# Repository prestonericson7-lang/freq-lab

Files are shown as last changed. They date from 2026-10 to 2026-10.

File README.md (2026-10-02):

# freq-lab

**A GPS-disciplined space-weather monitoring stack, built on an FPGA.**

An 8-station VLF solar-flare receiver that watches U.S. Navy transmitters for the
ionospheric signature of a solar flare, lightning geolocation by time-of-arrival across
stations, a 30 MHz riometer for cosmic-noise absorption, and a live multi-station
dashboard — all timed to GPS and verified to the bit before it touches hardware.

Verilog on a Zynq-7020 (PZ7020-StarLite), firmware on Teensy 4.1 / ESP32 / STM32, Python
host tools and a browser dashboard, plus the supporting instrumentation: a NIST
SP 800-90B-tested hardware random number generator, a digital lock-in amplifier, a
coincidence photon counter and a two-channel correlator.

**Every design is verified before it touches hardware:**

- **343 automated checks, all green**, in one command: `python run_all_tests.py`
- Two FPGA bitstreams that **close timing in Vivado 2026.1 with zero critical warnings**
- FPGA simulations checked **bit-exact against independent Python reference models**
- Firmware signal processing lifted into headers and **tested on a PC** (no hand-waving)

I don't overclaim. **Nothing here has run on real hardware yet** — everything is compile-,
simulation- or model-verified, and [STATUS.md](STATUS.md) says exactly what's proven and what
still needs a bench. When I say it works, there's a logged test behind it.

**Start here:** [STATUS.md](STATUS.md) (what's verified) · [WIRING.md](WIRING.md) (every pin,
every board) · [docs/station-setup.md](docs/station-setup.md) (build the VLF receiver station).

Toolchain to build/run it yourself: Python 3 (numpy, pyserial, matplotlib for plots) for the host
tools; the Arduino IDE or `arduino-cli` with the Teensy, ESP32 and STM32 cores for the sketches;
Xilinx Vivado (tested 2026.1) for the FPGA bitstreams, or just load the pre-built `.bit` files in
`fpga/*/build/`; Icarus Verilog + g++ to re-run the simulations and PC tests.

| Folder | Runs on | What it does | Checked |
|---|---|---|---|
| `teensy/resonance_sweep` | Teensy 4.1 + MPU-6050 + any exciter | Swept-sine lock-in, 0.05–400 Hz: resonance curve, Q, phase-locked tracking, ring-down | Compiles. Against a simulated resonator: f0 37.281 vs 37.271 Hz, Q 18.0 vs 18.0, tracker followed a drift from 37.3 to 38.0 Hz, ring-down time exact |
| `teensy/body_resonance` | Teensy 4.1 + up to six MPU-6050 | Vibration spectra, transfer function between two points on a body or structure, heartbeat recoil (ballistocardiogram) | Compiles. Simulated: 7 Hz line read 4997 µg of 5000; transfer peak 3.95 at 4.88 Hz vs 4.03 at 4.92; heart rate 72.0 of 72 |
| `teensy/hemisync_gen` | Teensy 4.1 + headphones | Six binaural tone pairs, exact beat frequencies, pink/surf noise, blind binaural / monaural / sham sessions | Compiles. Synth output measured: 100.000 / 104.000 Hz, beat 4.000 Hz, noise −10.0 dB |
| `teensy/elf_logger` | Teensy 4.1 + amplifier + coil or electrodes, GPS optional | 0.25–45 Hz spectrum logger with mains rejection, SRI's 19 bands, the first three Earth-ionosphere modes, GPS-stamped raw waveform | Compiles. Simulated front end with 1 V of mains on it: a 2 µV line read 1.4135 µV rms of 1.4144; noise floor within 3 %; 240 Hz mains harmonic did not fold into the band; 204 of 204 GPS second marks placed on the right sample |
| `teensy/strobe_driver` | Teensy 4.1 + LED(s) | Flashing-light driver, 0.1–100 Hz, randomized trial blocks (SRI's 0 / 6 / 16 Hz layout), glide, flash and trial markers, light-sensor check | Compiles. Every 50 µs tick simulated: 16 Hz period and width exact, 36 trials of exactly 10.00000 s with 0 / 60 / 160 flashes, blind order kept off the screen and matching the SD key |
| `teensy/cc1101_scanner` | Teensy 4.1 + CC1101 | Sub-GHz spectrum scanner, 300–928 MHz, variable RBW, peak hold, CSV sweep export | Compiles (Teensyduino 1.62, RadioLib 7.7.1) |
| `fpga/lockin` | PZ7020-StarLite (Vivado) | DDS + sigma-delta drive + on-chip 12-bit ADC + digital lock-in + resonance tracker, UART-controlled, up to about 100 kHz | Simulates end to end (iverilog): amplitude within 0.1 %, lag within 0.4°, tracker pulled 19.0 kHz onto a 20.0 kHz resonance. Synthesizes for xc7 (yosys). Vivado 2026.1: builds, timing met (WNS +11.9 ns at 50 MHz), 3.6 % LUTs, 0 critical warnings, ~0.13 W. Not yet run on hardware |
| `fpga/photon_counter` | PZ7020-StarLite (Vivado) | Coincidence photon counter: dual detectors, programmable coincidence window, singles + coincidence counts, elapsed clock, fan PWM, UART register protocol | Simulates end to end (iverilog): 12 checks pass — ID read, window write/readback, start/stop, singles and coincidence counts checked exactly (same-clock pairs counted, each pulse in at most one pair, none outside the window), error handling. Vivado 2026.1: builds, timing met (WNS +11.6 ns), 1.1 % LUTs, 0 critical warnings, ~0.11 W. Not yet run on hardware |
| `fpga/correlator` | PZ7020-StarLite (Vivado) | Two-channel cross-correlator: dual XADC (VAUX1 + VAUX9, ~195 kS/s each), DC-removed accumulation, circular-buffer lag queries, GPS PPS timestamping, fan PWM, UART register protocol | Simulates end to end (iverilog): 7 tests pass — ID read, live ADC reads, 100-sample acquisition with sin/cos test signals, accumulator readback (N=100 exact), lag query, error handling, GPS PPS counter. Vivado 2026.1: builds, timing met (WNS +8.1 ns), 2.4 % LUTs, 0 critical warnings, ~0.12 W; channel B is JM1-9/11 (E18/E19). Known limitation: nonzero-lag queries wrap around the 256-sample buffer (lag-0 coherence is exact). Not yet run on hardware |
| `fpga/vlf_sid` | PZ7020-StarLite (Vivado) | 8-station VLF solar-flare (SID) receiver: XADC at 390.6 kS/s, eight NCO + CIC channels (NLK, NPM, NAA, NML, NAU, NWC, JJI + a noise reference), power per GPS second, lightning-spike and clipping monitors, UART register protocol | Simulates end to end (iverilog): 33 testbench checks pass, and every decimated I/Q value of all 8 channels matches a bit-exact Python model; agrees with an ideal floating-point receiver within 0.003 dB, 80 dB rejection 400 Hz off-channel. Vivado 2026.1: builds, timing met (WNS +6.3 ns), 17 % LUTs, 50 DSPs, 0 critical warnings, ~0.15 W. Not yet run on hardware |
| `fpga/vlf_sid_v2` | PZ7020-StarLite (Vivado) | vlf_sid plus lightning (sferic) capture: threshold trigger, GPS-second + 20 ns clock stamps, 64-sample pre/post-trigger snapshots, 32-event FIFO, UART registers 40–49 and 60–7F; for a time-of-arrival lightning network | Simulates end to end (iverilog): 59/59 testbench checks (all of v1's + events over the UART), 19/19 Python checks (all of v1's + triggers at the predicted samples, every event's GPS second, exact 20 ns count, polarity, peak and all 64 snapshot samples vs the stimulus). Vivado 2026.1: builds, timing met (WNS +4.5 ns), 17.9 % LUTs, 7.5 BRAM tiles, 50 DSPs, 0 critical warnings, ~0.16 W. Not yet run on hardware. See `fpga/vlf_sid_v2/README.md` |
| `stm32/rf_resonance` | STM32 + SX1262 (DX-LR20 kit) | RF resonance probe: CW + swept-frequency transmission from one radio to another, measures insertion loss vs frequency to find cavity or tissue resonances | Compiles with arduino-cli (STM32 core 3.0.0 + RadioLib 7.7.1) for F103C8 (63.8 KB, 97 % flash) and F411CE: core 3.x needs RadioLib's pin casts, passed by `stm32/rf_resonance/build.bat` (the plain arduino-cli build fails in RadioLib's HAL). MAX_SWEEP 500 to fit the F103C8's 20 KB RAM; raise to 2000 on boards with ≥64 KB |
| `tools/lockin_host.py` | PC (Python + pyserial) | Sweeps, Q, tracking and delay calibration for the FPGA lock-in | Run against a software model of the FPGA: f0 439.93 of 440, Q 39.97 of 40 |
| `tools/photon_host.py` | PC (Python + pyserial) | Live counts, run management, accidental subtraction, CSV export for the photon counter | Not yet tested against hardware |
| `tools/correlator_host.py` | PC (Python + pyserial + numpy) | Acquisition, lag sweep, coherence computation, CSV/plot export for the correlator | Not yet tested against hardware |
| `tools/vlf_host.py` | PC (Python + pyserial, matplotlib for plots) | VLF receiver: info, input level, 10–50 kHz station scan, 1-second CSV logging with GOES X-ray flux, plots; `--station/--push` upload to the server; `sferics` (v2) logs strokes with UTC to the microsecond + 20 ns clock + snapshot | Run against a simulated board: scan found and named the stations, GPS sample-clock correction worked (+29.7 ppm of +30), GOES feed fetched and plotted. `tools/test/test_vlf_host.py` (fake v2 board + stub server): 16/16 — uploads, three strokes stamped within 20 ns of the injected times, queued delivery through an outage. Not yet tested against hardware |
| `tools/sid_detect.py` | PC (Python) | Solar-flare (SID) detector: trend-following baseline, 20-s mean onset confirmation, frozen baseline during events, 2-channel sustain, GOES confirmation, multi-station flag; also runs standalone over a CSV | `tools/test/test_sid_detect.py`, a synthetic day with 9 dB sunrise/sunset ramps, 200 lightning spikes, a one-channel step and two flares (+3.2, −2.0 dB): 14/14 — both flares found within 90 s of onset at +3.55 / −2.03 dB, 0 false events, GOES class C4.2 confirmed on the right one, multi-station flag right |
| `tools/sid_server.py` + `dashboard/index.html` | PC (Python stdlib only) | Station network server: SQLite store, JSON API, background flare detector + GOES fetcher, cross-station stroke matching (3 ms), and a dependency-free live dashboard (levels, GOES, strokes/min, alerts, time-of-arrival table) | `tools/test/test_sid_server.py`: two stations × 3 h ingested, strokes matched across stations to 1200 µs, detector creates GOES-confirmed multi-station alerts without duplicates, every endpoint and the dashboard served, bad input refused |
| `tools/riometer_host.py` | PC + RTL-SDR (`rtl_power`) | 30 MHz riometer / 245 MHz solar-burst logger: band power with interferer rejection, sidereal quiet-day curve (upper quartile over 7 days), absorption or enhancement in dB, CSV, upload | `tools/test/test_riometer.py`, 3 sidereal days synthetic with a +20 dB interferer bin and a 2.5 dB absorption event: 8/8 — band power within 0.23 dB of the true sky with the interferer dropped, the event read 2.56 dB, nothing outside it above 0.25 dB |
| `torsion_pendulum` | 2-liter bottle + 3D-printed parts + ESP32-S3 CAM (GC2145) + PC | SRI's 1974 bell-jar torsion pendulum test: sealed, static-shielded, backlit rotor tracked by the camera (rotor angle against two reference squares), blind random PUSH/REST schedule, hash-chained session log, exact randomization statistics, empty-room and warm-bottle controls | Parts watertight and fit-checked; tracker on synthetic frames 0.1-0.2 mrad/frame, camera movement cancelled; firmware compiles (Arduino-ESP32 3.3.12 and 2.0.17); statistics give 5 % false alarms on 200 simulated null sessions. Not yet run on hardware. See `torsion_pendulum/README.md` |
| `teensy/fpga_uart_bridge` | Teensy 4.1 | USB to FPGA serial pass-through | Compiles |
| `teensy/vlf_station` | Teensy 4.1 + vlf_sid FPGA + GPS | GPS-aware station bridge: passes the FPGA UART to the PC AND reads GPS NMEA (Serial2, pin 7) + 1PPS (pin 2) so `vlf_host.py --gps-bridge` stamps windows with true GPS UTC; `@gps`/`@pps`/`@id` bridge commands. For the full-rig station (FPGA + Teensy + ESP32 + SDR + GPS) — see `docs/station-setup.md` | Compiles (50 KB). NMEA parser PC-tested (`teensy/vlf_station/test/pc_test.cpp`, 11/11). Not yet run on hardware |
| `teensy/schumann_monitor` | Teensy 4.1 + ADS1256 (24-bit) + coil preamp + ball antenna | Two-channel ELF monitor: H and E multiplexed at 1000 SPS each, mains notches + 45 Hz low-pass, 4096-point Welch spectra, the five Schumann modes (centre Hz, pT/√Hz, floor ratio), E/H wave impedance with coherence at modes 1–2, GPS stamps, SD, JSON reports | Compiles (Teensyduino 1.62): 105 KB code, 145 KB RAM1 free. Filters and mode finder are the ones verified in `elf_logger` on a simulated front end. Not yet run on hardware |
| `esp32/schumann_gen` | ESP32 (DAC) or ESP32-S3 (PWM) + DC-coupled coil driver | Calibrated ELF field generator: 7.83 Hz + 4 harmonics (8 kS/s synthesis), current-sense field calibration in µT (coil geometry), closed-loop `target`, blinded sham sessions with a SHA-256 commitment, magnetophosphene sweep/ramp mode with a threshold button, phone web page (AP) | Compiles for esp32 (74 % flash, 15 % RAM) and esp32s3. Not yet run on hardware |
| `tools/schumann_host.py` | PC | Monitor host: reports to CSV, one-line summaries, upload to the server as kind `schumann`, live spectrum, 24 h+ history plots | `tools/test/test_schumann_host.py` (fake monitor + stub server): 6/6 |
| `teensy/rf_survey` | Teensy 4.1 + AD8318 log detector (1 MHz–8 GHz) | RF survey meter: 50 kS/s detector sampling, power-mean/peak dBm and µW/cm² per second (antenna aperture), envelope spectra 0.06–125 Hz and 12 Hz–25 kHz with named modulation lines (Wi-Fi beacon 9.77 Hz, LTE, DECT, Bluetooth, mains), pulse-interval histogram with a hysteresis detector, two-point calibration, GPS-tagged survey rows | Compiles (102 KB). Arithmetic PC-tested (`teensy/rf_survey/test/pc_test.cpp`, 18/18): calibration fit, aperture maths, power-mean level, pulse histogram on a synthetic Wi-Fi+LTE waveform (10 ms frame on top at 6 dB, 97 beacon intervals at 25 dB), peak finder and naming. Not yet run on hardware |
| `tools/rf_survey_host.py` | PC | Survey CSV, map coloured by µW/cm² (or level vs time without GPS), envelope-spectrum capture and plot, pulse listing | `tools/test/test_rf_survey_host.py` (fake meter): 7/7 |
| `teensy/sleep_cue` | Teensy 4.1 + EEG front end (+ EMG), earbuds | Closed-loop slow-oscillation cueing (Ngo 2013) + targeted memory reactivation: 30-s deep-sleep gate, SO trough detector (filter-delay compensated), cue 0.5 s after the trough, 2.5 s refractory + 6/min cap + arousal pause, SHA-256-sealed word-pair split, blinded stim/sham nights | Compiles (115 KB). Signal processing PC-tested (`teensy/sleep_cue/test/pc_test.cpp`, 22/22) on a synthetic night: gate, SO detection (≥95 µV caught, ≤65 µV rejected), cue timing (worst 8 ms), rate cap, arousal pause, SHA-256 vectors. Not yet run on hardware |
| `tools/sleep_cue_score.py` | PC | Blind scoring of a word-pair night: checks the SHA-256 commitments before scoring, permutation test of cued vs uncued recall | `tools/test/test_sleep_cue_score.py`: 8/8 (5 % null, power, commitment refusal) |
| `teensy/kirlian_logger` | Teensy 4.1 + GSR/FSR/photodiode front ends (HV rig external) | Controlled Kirlian: logs skin conductance, contact pressure and corona brightness per exposure, fits corona = moisture + pressure and reports R² and the residual; interlocks the HV (enable only during an armed exposure) but never generates it | Compiles (88 KB). Fit PC-tested (`teensy/kirlian_logger/test/pc_test.cpp`, 8/8): recovers coefficients, drops R² and recovers a hidden component, refuses singular/collinear inputs. Not yet run on hardware |
| `teensy/nuisance_logger` | Teensy 4.1 + MPU-6050 + fluxgate + mic + mains pickup | Logs a signal beside vibration, B-field, sound and mains and vetoes the ordinary cause: per-sample windowed correlation flags when an excursion is explained by a nuisance (the 8 Hz mount resonance, #133; 60 Hz everywhere) | Compiles (92 KB). Veto core PC-tested (`teensy/nuisance_logger/test/pc_test.cpp`, 10/10): genuine signal not vetoed, vibration-as-signal and continuous/impulsive mains vetoed, no false blame. Not yet run on hardware |
| `fpga/trng` | PZ7020-StarLite (Vivado) | Ring-oscillator TRNG (#73): 16 ring oscillators → SP 800-90B health tests (Repetition Count + Adaptive Proportion) → von Neumann debiaser → LFSR conditioning → 32-bit words → FIFO; on-chip temperature and VCCINT logged; output withheld while a health test is tripped | Simulates end to end (iverilog, entropy backdoor): 9 testbench + 33 Python checks, every output word, counter, health flag and FIFO read bit-exact vs a model across balanced/stuck/biased streams. Vivado 2026.1: builds, timing met (WNS +12.6 ns), 570 LUTs (1 %), 0 critical warnings, the 16 ring-oscillator loops flagged allowed, ~0.11 W. Not yet run on hardware. See `fpga/trng/` |
| `tools/trng_host.py` | PC | TRNG host: info + die temp, word/byte streaming, live health, config, `selftest` (125 kB sample, monobit/runs/chi-square + die-temp log, the SRI 1980-style certification run) | `tools/test/test_trng_host.py` (fake board): 14/14 (health-alarm stop, config, streaming, stats pass good / fail biased) |
| `tools/blindhash.py` | PC | Blind randomization + pre-posted SHA-256 commitment (#158): draw a schedule, seal it, verify it, score it (two-sided permutation by default; one-sided only with a pre-registered direction) | `tools/test/test_blindhash.py`: 17/17 (tamper-evident, calibrated null, order-independent p — a real statistical bug the red-team pass caught) |
| `tools/shield_audit.py` | PC | Shielding attenuation vs frequency (#134, #160) from lock-in / CC1101 / VLF sweep CSVs, with skin-depth theory: shows the ELF hole in an RF-tight cage | `tools/test/test_shield_audit.py`: 10/10 (attenuation maths, format reading, copper/mu-metal skin depth) |
| `tools/cavity_readout_host.py` | PC + SX1262 pair / RTL-SDR | Passive-cavity resonator test-tone readout (#190, #191, the Great Seal demo): recover a known test tone off a tuned cavity, measure recoverable SNR vs illuminator power | `tools/test/test_cavity_readout.py`: 11/11 (carrier finding, AM/PM demod, SNR-vs-depth, power-step threshold) |

## Teensy sketches: first run

Arduino IDE, board Teensy 4.1, upload, open the serial monitor, type `help`.

- **resonance_sweep**: fix the MPU-6050 and the exciter to the object, then
  `amp 0.2`, `sweep 5 200 100 log`, `ringdown <peak Hz> 5 5`, `track 60`.
- **body_resonance**: `scan`, then `spec 60` for spectra, `tf 0 240` for the transfer
  function from sensor 0 to the others, `bcg 2 120` for the heartbeat recoil at sensor 2.
- **hemisync_gen**: `preset patent4`, `vol 0.15`, `run 10`. For a test that means something:
  `blind patent4 10`, write down what you noticed, then `reveal`.
- **elf_logger**: `gain 1000`, `mains 60`, `raw on`, `start 300`. `live` prints the full spectrum.
- **strobe_driver**: read the warning at the top of the file first. `arm`, `arm yes`,
  `rate 10`, `on`, `check 4`, `off`. SRI's layout: `blind on`, `sri`.
- **cc1101_scanner**: `sweep 433 434 12` scans 433–434 MHz with 58 kHz RBW.
  `peak`, `hold on`, `csv` dumps the last sweep.
- **schumann_monitor**: `gain h 1000`, `pga h 8`, `coil 30000 0.0158`, `ecal 1.0`,
  `start 60`. `live` prints the full H/E spectrum; `json on` for the host tool.
- **rf_survey**: `cal -20` then `cal -40` with known levels, `ant 2.44 2.0`,
  then `level`, `spec slow 60` (Wi-Fi beacon at 9.77 Hz), `pulses 30`, `survey on`.
- **sleep_cue**: battery power only with electrodes on. `gain 1000`, `vol 0.05`,
  `test` to set the volume, `pairs 60`, then `night` (blind) or `mode sham` + `start`.
- **nuisance_logger**: `window 64` (for 60 Hz) or `256` (for 8 Hz), `start 300`;
  `report` shows which nuisance explained the signal excursions.
- **kirlian_logger**: build the interlocked HV rig first. `gsrcal`, `vary moist 8`,
  `expose` each, then `fit` for R² and the residual. HV safety is on you.
- **vlf_station**: the GPS-aware bridge for the VLF station — no serial commands of
  its own; flash it, then talk to the FPGA through it with `vlf_host.py`. See below.

## STM32 + SX1262: RF resonance probe

Arduino IDE with STM32 board package + RadioLib. Wire the DX-LR20 kit's SPI/BUSY/DIO1
pins to the STM32 (pin map at the top of `rf_resonance.ino`). Power both radios, connect
one to each STM32, serial monitor on each.

On the transmitter: `mode tx`, `cw 915.0`, then on the receiver: `mode rx`, `measure`.
For a swept measurement: transmitter `sweep 900 928 0.1`, receiver `sweep 900 928 0.1`.

The idea is to put a sample (tissue, water, crystal, cavity) between the two antennas and
look for absorption dips or resonance peaks in the insertion-loss-vs-frequency curve.

## FPGA lock-in

### Wiring (JM1, even-numbered row)

```
JM1-2  3.3 V        JM1-4  GND
JM1-6  ADC +   0 .. 1.0 V ONLY          JM1-8  ADC -   -> GND at the sensor
JM1-10 drive   -> 1 kΩ -> node -> 10 nF -> GND      (node = analog sine, 0..3.3 V)
JM1-12 sync    square wave at the drive frequency
JM1-14 FPGA TX -> adapter RX (or Teensy pin 0)
JM1-16 FPGA RX <- adapter TX (or Teensy pin 1)
```

Fan pins JM1-5 / JM1-7 behave exactly as in `fan_top.v`, so the fan keeps running.

Loop-back for a first test and for `cal`: node -> 33 kΩ -> JM1-6, and 10 kΩ from JM1-6 to GND
(divides by 4.3, so even 3.3 V at the node is 0.77 V at the pin). JM1-8 to JM1-4.

A sensor goes in the same way: bias JM1-6 to about 0.5 V (56 kΩ to 3.3 V, 10 kΩ to GND),
couple the sensor through 100 nF, and keep its swing under ±0.4 V.

### Build and load

```
cd fpga/lockin
vivado -mode batch -source build.tcl      # writes lockin_top.bit
vivado -mode batch -source program.tcl    # boot jumper on JTAG, JTAG Type-C connected
```

LED1 blinks once a second when the fabric is running. LED2 toggles on every finished
lock-in window.

### Use

```
pip install pyserial
python tools/lockin_host.py COM7 id
python tools/lockin_host.py COM7 cal
python tools/lockin_host.py COM7 sweep 50 5000 200 --log --amp 0.2 --out curve.csv
python tools/lockin_host.py COM7 track 440 --step 0.05
python tools/lockin_host.py COM7 off
```

Drive range: micro-hertz steps up to about 100 kHz (the RC filter's corner is 16 kHz;
change the capacitor for higher drive frequencies). ADC rate 390.6 kS/s.

### Re-run the simulation

```
cd fpga/lockin
iverilog -g2005 -DSIMULATION -o tb sim/tb_lockin.v hdl/*.v && vvp tb
```

## FPGA photon counter

Coincidence counter for biophoton detection experiments (Gurwitsch mitogenetic radiation,
SRI-style photomultiplier setups). Two detector inputs, programmable coincidence window,
64-bit singles and coincidence counters, elapsed clock for rate computation.

### Wiring (JM1, even-numbered row)

```
JM1-2  3.3 V             JM1-4  GND
JM1-6  det_a  detector A pulse input (3.3 V logic, rising edge = photon)
JM1-8  det_b  detector B pulse input
JM1-10 gate   counting enable (active high, tie to 3.3 V for always-on)
JM1-14 FPGA TX -> adapter RX
JM1-16 FPGA RX <- adapter TX
```

Fan on JM1-5 / JM1-7.

### Build and load

```
cd fpga/photon_counter
vivado -mode batch -source build.tcl
vivado -mode batch -source program.tcl
```

### Use

```
python tools/photon_host.py COM7     # connects, prints the ID, then gives a photon> prompt
photon> window 10                    # coincidence = A and B within ±10 ticks (±200 ns)
photon> run 10                       # count for 10 s, then print singles, coincidences, elapsed
photon> rate                         # counts per second
photon> accidental                   # chance overlaps vs real coincidences
photon> csv run1.csv 60 5            # five 60 s runs saved to run1.csv
photon> quit
```

### Re-run the simulation

```
cd fpga/photon_counter
iverilog -o tb sim/tb_photon.v hdl/*.v && vvp tb
```

## FPGA two-channel correlator

Cross-correlator for ELF two-station experiments. Two on-chip XADC channels
(VAUX1 + VAUX9, ~195 kS/s each), DC-removed accumulation via the identity
`sum((a-ma)(b-mb)) = sum(ab) - sum(a)*sum(b)/N`, circular buffer for lag queries
up to ±MAX_LAG samples, GPS PPS timestamping for multi-station synchronization.

### Wiring (JM1, even-numbered row)

```
JM1-2  3.3 V             JM1-4  GND
JM1-6  VAUX1+  channel A analog input (0..1.0 V)
JM1-8  VAUX1-  -> GND at sensor
JM1-9  VAUX9+  channel B analog input (0..1.0 V)   (odd row, ball E18)
JM1-11 VAUX9-  -> GND at sensor                    (odd row, ball E19)
JM1-18 gps_pps GPS 1PPS input (3.3 V logic, optional)
JM1-14 FPGA TX -> adapter RX
JM1-16 FPGA RX <- adapter TX
```

Fan on JM1-5 / JM1-7.

### Build and load

```
cd fpga/correlator
vivado -mode batch -source build.tcl
vivado -mode batch -source program.tcl
```

### Use

```
python tools/correlator_host.py COM7  # connects, prints the ID, then gives a corr> prompt
corr> adc               # live reading of both inputs (about 2048 = 0.5 V on the bias network)
corr> window 100000     # samples per window: 100000 = 0.5 s, up to about 1900000 = 10 s
corr> stream 5          # 5 windows back to back, coherence (-1 .. +1) for each
corr> lagplot 16        # last window's correlation at offsets -16..+16 samples (5.12 us each)
corr> csv out.csv 50    # 50 windows saved to out.csv
corr> quit
```

### Re-run the simulation

```
cd fpga/correlator
iverilog -DSIMULATION -o tb sim/tb_correlator.v hdl/*.v && vvp tb
```

## FPGA VLF solar-flare receiver (vlf_sid)

Listens to 8 Navy VLF transmitters at once and logs their strength every second, so
a solar flare shows up as a step in the daytime stations at the moment the GOES X-ray
curve rises. Same JM1 wiring as the lock-in (antenna preamp on JM1-6/8, UART on 14/16,
optional GPS PPS on 18). Full details, front end and register map:
[fpga/vlf_sid/README.md](fpga/vlf_sid/README.md).

```
fpga\build_vlf_sid.bat                          (double-click: Vivado build)
python tools/vlf_host.py COM7 level             set the preamp gain
python tools/vlf_host.py COM7 scan              10-50 kHz spectrum, names the stations
python tools/vlf_host.py COM7 log --goes        1 line per second + GOES X-rays to CSV
python tools/vlf_host.py plot vlf_2026-10-02.csv --goes goes_2026-10-02.csv
```

**Version 2 (`fpga/vlf_sid_v2`)** adds lightning time-of-arrival capture (20 ns
GPS-relative stamps) on top of everything above; build it with
`fpga\build_vlf_sid_v2.bat`. **For a full receiver station** (FPGA + a GPS-aware
Teensy bridge + an RTL-SDR riometer complement + GPS/PPS), including the exact
wiring, the GPS convention and `vlf_host.py --gps-bridge` for true GPS time, see
[docs/station-setup.md](docs/station-setup.md). Product-line kit docs for the
space-weather, Schumann, RF-survey and biofeedback lines are in [docs/](docs/).

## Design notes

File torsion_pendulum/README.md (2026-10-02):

# Torsion pendulum in a bottle (FOIA list #2)

SRI reported in 1974 that a person could disturb a torsion pendulum sealed in a bell
jar. The pendulum was three 100 g balls on a metal fiber, read out by a laser 1.5 m
away. The change from baseline was "often 5:1" from 1 m and "typically 2:1" from
12 m. The runs were randomized, but no statistics were done.

This rig repeats that test with the known culprits handled:

- **Static electricity:** a grounded foil shield blocks it.
- **Body heat:** a warm-water-bottle control session measures how much it moves the rotor.
- **Drafts:** the chamber is sealed.
- **Camera movement:** reference squares cancel it out.
- **Wishful analysis:** the random schedule is fixed before each session, every session is logged, and the statistics are exact.

How to read the result:

- **Grade C claim.** No one has shown it works under conditions like these. A clean
  null result is the expected outcome, and it is a real result.
- **An effect would show in one session.** SRI's claimed 2:1 to 5:1 effect is huge
  next to this rig's noise.

```
              knob (sets the zero)      ESP32-S3 CAM, lens down
                    |                       |
   lid  ===========[O]====[ sled  window ]=====      <- 132 mm plate
          \         |                        /       <- 45 deg cone: the top rim of the sleeve wedges on it
           \________|_______________________/           (any rim 85-120 mm across); tape over the joint
            |       |                       |
            |     fiber (one strand of      |        the bottle's straight middle, cut off top and bottom
            |     jumper wire)              |        ("the sleeve", 150-230 mm tall), foil-wrapped outside
            |       |                       |
            |  [==O===o===O==]  rotor: 2 quarters sealed inside, 20 mm above the floor
            |  []  --paper--  []            |        paper target glued to the floor, squares at +/-30
           /________________________________\        <- 45 deg cone: the bottom rim slides over it
   base   |          |  LED  |               |       <- 30 mm base; 94 mm backlit window in the floor,
          |__________|_______|_______________|          open underneath; the LED sits on a puck on the table
```

A real 2-liter bottle is 100-120 mm across and 300-330 mm tall depending on the brand,
with a five-footed base that is domed inside and a long curved shoulder. So the bottle
is used only for its clear wall: it is cut twice, and the printed lid and base each
carry a 45-degree cone that any rim between 85 and 120 mm wedges onto. The floor is
printed and flat, and nothing in the design depends on the bottle's diameter.

## Parts

| Item | Notes |
|---|---|
| `torsion_pendulum.3mf` | Bambu Studio project, 4 plates: lid, base, rotor, knob + camera sled + LED puck. PLA, white for the base (the floor's window is the light diffuser). The rotor is set to 100 % infill and needs a **pause at 3.40 mm** to drop one US quarter into each pocket. |
| 2-liter soda bottle | Empty, clean, label off. Any brand: only its straight middle is used. |
| ESP32-S3 CAM | Your Meshnology GC2145 board, plus a USB-C cable. |
| 2 US quarters | The rotor's weights. |
| Fiber | One strand pulled out of a stranded jumper wire, about 25 cm long. A strand from a usual 26 AWG Dupont jumper is 0.16 mm and gives a swing period of about 5 s; a 28 AWG strand (0.127 mm) gives about 8 s and 2.5x the sensitivity. Thinner is better; `calibrate` measures whatever you use. |
| 5 mm white LED + 470 ohm resistor | Backlight, powered from the camera board's 5V and GND pins with female jumpers. A *diffused* (cloudy) LED lights the floor evenly; if yours is water-clear, scuff its dome with sandpaper. Use 220 ohm if the picture is too dark. |
| Aluminium foil + 1 jumper wire | Static shield around the sleeve, wired to the board's GND. |
| 2x M3x10 screws + 2x M3 nuts | Hold the camera sled to the lid. M3x12 also fits. |
| Hot glue or superglue, a glue stick | Fix the fiber ends and the camera board; the glue stick holds the paper target to the floor. |
| Clear tape | Seals the camera window and the two sleeve joints. |
| Plain printer paper | For `paper_target.pdf`, printed at 100 %. |

## Build

1. **Cut the bottle twice.** Stand it on a table and mark the lines with a marker held
   on a stack of books while you turn the bottle.
   - *Bottom cut:* about 40 mm up, just above the feet, where the body has become round.
     If your bottle has a grip or waist low down, cut above it.
   - *Top cut:* in the shoulder, where the bottle has narrowed to about 90 mm across
     (anywhere between 85 and 120 mm is fine; the lid's cone takes any of it). Cutting
     there keeps the most height.
   - Both rims must be round: not through a grip dent or a rib. Aim for a sleeve
     150-230 mm tall; 180-210 is typical. Trim the rims with scissors so they are even.
2. **Print the parts.** The plates are already oriented: lid top-face-down (cone up),
   base floor-down (its well opens upward), rotor flat, knob face-down. For the rotor
   (plate 3), drag the layer slider to 3.40 mm, right-click, and choose *Add pause*.
   When the printer pauses, drop one quarter flat into each pocket and resume.
3. **Paper target.** Print `paper_target.pdf` at 100 % ("Actual size"). Check that the
   scale bar measures 50 mm, cut out one 96 mm disc, and glue-stick it onto the base's
   floor with the two squares lined up with the small notch on the floor's edge.
4. **LED puck.** Push the LED up through the puck's centre hole from below until its
   flange seats in the recess; bend the legs flat into the groove, with the resistor
   on one leg, and run two wires out along the groove. (The two outer holes are for
   extra LEDs if one is not bright enough.) Put the puck on the table, LED up, and set
   the base over it with the base's wire channel over the wires.
5. **Lid.**
   - Put clear tape over the camera window from the *underside*.
   - Push 2 M3 nuts into the hex pockets under the lid.
   - Bolt the camera sled on top with the 2 M3x10 screws.
6. **Knob and fiber.** Glue one end of the strand about 6 mm into the hole at the tip
   of the knob's pin. Thread the fiber down through the lid's centre hole and seat the
   knob. Friction holds it; turning it sets the rotor's resting angle (ticks every 10°).
7. **Dry fit and measure.** Slide the sleeve's bottom rim over the base's cone and press
   it down until it wedges. Drop the lid's cone into the top rim. Measure from the table
   to the lid's top face: call it H. Take the lid off again.
8. **Hang the rotor.** The free fiber length, from the pin's tip to the top of the
   rotor's hub, is **H minus 74 mm**. Cut the strand 8 mm longer than that, push the
   extra all the way down the hub's hole and glue it. The rotor then hangs 20 mm above
   the floor; anywhere from 10 to 30 mm works.
   Let it hang overnight: a fresh copper strand creeps for a few hours, then settles.
9. **Shield.** Wrap the outside of the sleeve in one layer of foil and tape it. Tape the
   bare end of a jumper wire to the foil, and plug the other end into the board's GND.
10. **Close it up.** Lower the rotor into the sleeve and seat the lid's cone in the top
    rim. Turn the lid so its engraved arrow points the same way as the floor's notch
    (the squares then lie along the arrow). Run clear tape round both joints, from the
    printed part onto the bottle.
11. **Camera.** Lay the board camera-side down on the sled's rails, lens over the window,
    with the rest of the board pointing outward, away from the knob. Tack it with hot
    glue, or use zip ties through the slots. Wire the LED's two leads to the board's
    5V and GND.
12. **Flash the board.** In the Arduino IDE, open `firmware/torsion_cam/torsion_cam.ino`
    and pick these settings, then upload through the USB-C port marked COM/UART:
    - Board: "ESP32S3 Dev Module"
    - PSRAM: "OPI PSRAM"
    - Flash Size: "16MB"
    - USB CDC On Boot: "Disabled"

    The firmware finds the camera's pin layout by itself.

## Set up and check (PC: `pip install pyserial numpy scipy pillow matplotlib`)

```
python host/torsion_host.py COM8 snap        # saves a PNG of what the camera sees, with what it measures
python host/torsion_host.py COM8 live        # live angle, swing and period
python host/torsion_host.py COM8 calibrate   # follow the prompts: one knob tick clockwise, then back
```

**Snap:** the PNG should show:

- the rotor outlined in red, whole, inside the lit window;
- both squares in blue boxes;
- the lit window circled in green.

Turn the knob until the rotor lies *across* the line of the squares, not along it.

**Calibrate** measures:

- the swing period (about 5 s with a 0.16 mm strand, 8 s with 0.127 mm) and how fast
  it dies out;
- the torsion constant, which turns angle into torque;
- which way "clockwise" reads on the camera.

## The experiment

Decide the plan before you collect any data, and stick to it. This is the default:

- 2 warm-bottle sessions (`--kind warm`);
- 10 empty-room sessions (`--kind empty`);
- 10 agent sessions (`--kind agent`), alternated with the empty ones.

Each session lasts 22 minutes:

- 5 minutes settling;
- 16 one-minute periods, 8 PUSH and 8 REST in random order;
- 1 minute tail.

```
python host/torsion_host.py COM8 session --kind agent    # sit 1 m away; high beep = PUSH (will it clockwise),
                                                         # double low beep = REST. Stay seated the whole time.
python host/torsion_host.py COM8 session --kind empty    # start it, then leave the room within 2 minutes
python host/torsion_host.py COM8 session --kind warm     # 37 C water bottle onto the 1 m spot at PUSH,
                                                         # away to the far side at REST
python host/torsion_host.py report --plot                # checks the log, then every result and the combined score
```

**Where to set up:**

- A solid table, away from heating and AC vents, windows and direct sun, and the PC
  (it is warm).
- Mark the 1 m spot on the floor.

**What each session prints:**

- **D:** the PUSH-minus-REST deflection in mrad, with clockwise positive, and the
  torque it means.
- **p:** the exact chance probability, counted over all 12,870 possible schedules.
- **Swing ratio:** PUSH/REST, the number SRI reported as 2:1 to 5:1.

**Decision rule (fixed now):** call it an effect only if both of these hold:

- the agent sessions' combined Z is at least 2.33 (p < 0.01);
- the empty-room sessions' combined Z is under 1.64.

The warm-bottle sessions show what a real physical push looks like on this rig.

**Integrity checks.**

- Before each session runs, its schedule's fingerprint goes into
  `torsion_data/commitments.txt`. Text it to someone if you want an outside record.
- Every session is chained into `torsion_data/sessions.jsonl` with its data file's hash.
- `report` fails loudly if a session is dropped, a data file is edited, or a schedule
  doesn't match its fingerprint.

## Files

| Path | What |
|---|---|
| `cad/torsion_pendulum.3mf` | the print project (4 plates) |
| `cad/*.stl`, `cad/assembly.png` | single parts and a picture of the assembly |
| `cad/paper_target.pdf` | the floor target, two per page |
| `cad/parts.py`, `cad/build.py` | the part generator (Python + manifold3d), to change any dimension |
| `firmware/torsion_cam/` | ESP32-S3 sketch: camera, tracker, serial protocol |
| `firmware/platformio.ini` | same sketch for PlatformIO |
| `host/torsion_host.py` | snap, live, calibrate, session, report, analyze, simulate |
| `sim/` | tracker test (synthetic camera frames) and a fake camera for testing the host |

## How it was checked

- **Bottle facts:** 2-liter bottles run 100-120 mm across and 300-330 mm tall
  (Wikipedia, "Two-liter bottle"); the common US one is 110 mm by 315 mm
  (dimensions.com); the base is a petaloid with a convex centre, not a flat floor
  (EP2555984B1). The cones take rims from 85 to 121 mm (lid) and 99 to 125 mm (base).
- **Parts:** every part is watertight and a single solid; the rotor's two sealed
  pockets are 974 mm3 each. Fit checks (`build.py`):
  - where each rim size wedges on each cone (a 104 mm rim: 9 mm below the lid, 3 mm
    below the floor);
  - the rotor clears the wall of the narrowest bottle by 11.6 mm;
  - the rotor's tips and the squares' tracking boxes stay inside the backlit window as
    the camera sees them, for sleeves from 150 to 230 mm;
  - the lid's cone hides none of the window; the camera's view cone clears the lid
    window with 2.2 mm to spare.
- **Rotor:** 16.5 g; moment of inertia 1.02e-5 kg m^2 (the PLA part is computed
  solid, which is why it's printed at 100 % infill).
- **Tracker** (same C++ the board runs), on synthetic camera frames of this exact
  layout, with the camera 165, 205 and 240 mm above the floor:
  - 0.05-0.19 mrad noise per frame;
  - a 10 mrad step measured as 9.77-9.78 against a true 9.77;
  - a 2 mrad turn of the camera itself cancelled to under 0.2 mrad;
  - the 175 mrad knob turn of the calibrate step followed without losing lock;
  - the rotor hung anywhere from 8 to 32 mm above the floor, lens fields of view
    from 48° to 62°, and image noise up to 5 counts all handled (at 40 mm the rotor's
    tips reach past the lit window and it is not found: keep to the fiber length above).
- **Firmware:** compiles with no warnings for the ESP32-S3 with both Arduino-ESP32
  3.3.12 (current) and 2.0.17. Both cores' camera libraries include the GC2145 driver.
- **Statistics:** across 200 simulated sessions with no effect, p < 0.05 came up
  5 % of the time, exactly as it should. A steady 0.3 mrad push reached p < 0.05 in
  42 % of single sessions.
- **Host program:** run against a simulated camera:
  - calibration recovered the period (8.03 s against 8.0) and Q (15.0 against 15);
  - sessions logged;
  - the report caught an edited data file and a deleted session.

Not yet run on the real hardware.

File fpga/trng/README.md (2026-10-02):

# trng — ring-oscillator TRNG with SP 800-90B health tests (experiment #73)

A true random number generator on the PZ7020-StarLite. SRI certified their
1980 generator with 500,000-sample control runs and logged the diode
temperature to 0.2 °C; this does the modern equivalent: a ring-oscillator
noise source, the NIST SP 800-90B health tests in hardware, von Neumann
debiasing, LFSR conditioning, and the on-chip temperature logged alongside.
It gives every psi/bioeffect experiment in the stack an auditable, tamper-
logged target picker.

## Pipeline

```
16 ring oscillators --XOR, metastability-hardened, decimated--> raw bits
   |
   +--> RCT (Repetition Count Test)   \  SP 800-90B health tests on the RAW stream;
   +--> APT (Adaptive Proportion Test) /  output is withheld while either is tripped
   |
   +--> von Neumann debiaser (01->0, 10->1, 00/11->drop)
   +--> LFSR conditioning (x^32+x^22+x^2+x+1)
   +--> 32-bit packer --> 64-word FIFO --> UART
```

* **RCT**: if a raw value repeats `RCT_CUT` times in a row (default 20), alarm.
* **APT**: in a window of `APT_WIN` raw bits (default 1024), if the count equal
  to the window's first bit reaches `APT_CUT` (default 660), alarm.
* Both latch a sticky alarm and a fail counter; a CTRL write clears them. While
  an alarm is latched, von Neumann stops, so biased or stuck entropy never
  reaches the host.

The ring oscillators are deliberate combinational loops (odd inverter chains),
kept with `ALLOW_COMBINATORIAL_LOOPS`; the entropy is their jitter against the
50 MHz sampling clock. Nothing in this design transmits.

## Verification

Ring oscillators can't be simulated (combinational loops), so `entropy_src.v`
has a simulation backdoor: the testbench feeds a chosen raw-bit stream and the
**whole deterministic pipeline** — health tests, debiaser, conditioner, packer,
FIFO, UART register file — is checked bit-for-bit against `sim/trng_model.py`.

```
cd fpga/trng/sim
python3 gen_files.py
iverilog -g2012 -DSIMULATION -o tb_trng tb_trng.v ../hdl/entropy_src.v \
         ../hdl/trng_core.v ../hdl/cmd_regs_trng.v ../hdl/uart.v
for s in balanced stuck biased; do vvp tb_trng +STIM=stim_$s.txt +LOG=log_$s.txt; done
python3 check_trng.py stim_balanced.txt log_balanced.txt \
                      stim_stuck.txt    log_stuck.txt \
                      stim_biased.txt   log_biased.txt
```

Results (9 testbench + 33 model checks, all pass):

| Stream | What it shows |
|---|---|
| balanced (4000 bits, 49.4 % ones) | full datapath: raw/VN counts, 31 output words and all 31 FIFO reads bit-exact, no health alarm |
| stuck (100 ones) | RCT trips (5 counts, re-arming every 20), 0 words pass |
| biased (72 % ones, runs capped at 15) | APT trips (112 counts), RCT does not — the test isolated |

Every output word, the von Neumann and raw counters, both health flags and
fail counts, and the FIFO DATA reads match the Python model exactly.

Vivado 2026.1 (xc7z020clg400-2, Oct 1 2026): builds, exit 0, **0 critical
warnings**. Timing met at 50 MHz (WNS +12.59 ns, hold +0.115 ns, 0 failing of
2289 endpoints). 570 LUTs (1.1 %), 705 flip-flops (0.7 %), 0.5 BRAM, 1 DSP, 8
IOBs. The 16 ring-oscillator loops are reported as `LUTLP-2 Combinatorial Loop
Allowed` (intentional, downgraded to a warning). 0.110 W, junction 26.3 °C.
Bitstream `build/trng.bit`. Not yet run on hardware.

## Build and load

```
fpga\build_trng.bat                       Vivado build (~2.5 min)
   Vivado Tcl shell:  cd P:/Downloads/freq-lab/fpga/trng ; source program.tcl
   (loads RAM only; a power cycle restores the board)
```

## Use

```
python tools/trng_host.py COM7 info          status, health, die temperature
python tools/trng_host.py COM7 get 16        16 random 32-bit words
python tools/trng_host.py COM7 bytes 1000000 r.bin
python tools/trng_host.py COM7 selftest      125 kB + monobit/runs/chi-square + die-temp log
python tools/trng_host.py COM7 config --rct 20 --apt-win 1024 --apt-cut 660
python tools/trng_host.py COM7 clear         clear a latched health alarm
```

## Register map (UART, 115200 8N1, `R aa` / `W aa dddddddd`)

| Addr | Name | | |
|---|---|---|---|
| 00 | ID | RO | 0x54524E31 ("TRN1") |
| 01 | CTRL | RW | bit0 RUN; writing bit8=1 also clears the health alarms (default 0x1) |
| 02 | STATUS | RO | bit0 RUN, bit1 RCT, bit2 APT, bit3 FIFO empty, bit4 full, bit5 underflow, [15:8] words available |
| 03 | DATA | RO | a 32-bit random word; **reading it pops the FIFO** (0 if empty) |
| 04 | RAW_CNT | RO | raw noise-source bits |
| 05 | VN_CNT | RO | von Neumann output bits |
| 06 | RCT_FAILS | RO | Repetition Count Test alarms |
| 07 | APT_FAILS | RO | Adaptive Proportion Test alarms |
| 08 | WORD_CNT | RO | 32-bit words produced |
| 09 | RCT_CUT | RW | RCT cutoff (default 20) |
| 0A | APT_WIN | RW | APT window (default 1024) |
| 0B | APT_CUT | RW | APT cutoff (default 660) |
| 0C | DIE_TEMP | RO | XADC temp code (T_C = code·503.975/4096 − 273.15) |
| 0D | VCCINT | RO | XADC VCCINT code (V = code·3.0/4096) |
| 18 | FAN_DUTY | RW | % (default 60) |
| 19 | FAN_RPM | RO | |

## Honest note on the conditioning

The LFSR conditioning whitens the output; it is not itself entropy. The
entropy is the ring-oscillator jitter, and the health tests run on the raw
bits before any conditioning (as SP 800-90B requires) so a failing noise
source is caught even though the LFSR would make its output look random. For a
certified entropy claim you would run the full SP 800-90B estimators on the raw
stream; `trng_host.py selftest` runs the cheaper SP 800-22-style checks on the
conditioned output as a sanity gate.

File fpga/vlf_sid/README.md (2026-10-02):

# vlf_sid — 8-station VLF solar-flare receiver (experiment #19)

US Navy VLF transmitters (NLK, NPM, NAA, NML, ...) send a constant-strength
signal that travels between the ground and the bottom of the ionosphere. When
a solar flare's X-rays hit the daytime sky, that ceiling drops within minutes
and every daytime station you receive jumps or dips by a few dB — a Sudden
Ionospheric Disturbance (SID). This design measures 8 stations at once, every
second (on GPS seconds if a GPS is connected), so the flare shows up as a step
in all of them at the same moment as the NOAA GOES X-ray curve.

The FPGA only listens. Nothing in this design transmits.

## What is in this folder

| File | What it is |
|---|---|
| `hdl/vlf_top.v` | top level: XADC, 8 channels, window timing, GPS PPS, LEDs, fan |
| `hdl/vlf_channel.v` | one station: NCO, mixer, 3-stage CIC (/1024), power per window |
| `hdl/sine_qrom.v` | quarter-wave sine table (generated by `sim/gen_files.py`) |
| `hdl/cmd_regs_vlf.v` | UART register file (same text protocol as the other designs) |
| `hdl/xadc_vaux1.v`, `uart.v`, `fan_pwm.v` | unchanged copies from the lockin/correlator |
| `constraints/vlf_jm1.xdc` | pins: same JM1 wiring as the lockin/correlator |
| `build.tcl`, `program.tcl` | Vivado build and JTAG load |
| `sim/` | testbench, stimulus generator, bit-exact and ideal reference models |
| `../build_vlf_sid.bat` | double-click to build with Vivado |
| `../../tools/vlf_host.py` | PC program: info, level, scan, log (+GOES), plot |

## Wiring (JM1)

| JM1 pin | FPGA ball | Signal | Notes |
|---|---|---|---|
| 2 | — | 3.3 V | powers the preamp's output stage |
| 4 | — | GND | |
| 6 | E17 | ANTENNA+ (VAUX1P) | preamp output, **0 to 1.0 V only**, rest at 0.5 V |
| 8 | D18 | ANTENNA− (VAUX1N) | preamp ground, wired at the preamp |
| 14 | B19 | UART TX | to the 3.3 V USB-serial adapter's RX |
| 16 | A20 | UART RX | from the adapter's TX |
| 18 | C20 | GPS PPS | 3.3 V 1PPS from a GPS module (optional) |
| 5 / 7 | H16 / H17 | fan PWM / tach | as in the other designs |

LEDs: R19 blinks at 1 Hz (running). V13 blinks once per finished window and
stays **on** if the last window clipped (antenna signal too big: lower the gain).
KEY1 held = fan 100 %.

## Front end (what goes between the antenna and JM1-6)

```
 loop antenna  -->  preamp ~60 dB, 10-50 kHz  -->  0.5 V bias  -->  100 ohm  -->  JM1-6
 (1 m square,       (low-noise rail-to-rail                          + 2.2 nF
  ~10 turns)         op-amp on the 3.3 V pin)                         to JM1-8
```

* A **loop** (1 m square frame, about 10 turns of insulated wire) picks up the
  magnetic field and ignores much of the house's electric noise. It is
  directional: its edge points at the stations it hears best.
* Run the preamp's last stage from **JM1-2 (3.3 V)**: then nothing it can do
  can put more than 3.3 V on the pin. Above 1.0 V the ADC just reads full
  scale (the LED tells you).
* The preamp must roll off above ~60 kHz (the ADC samples at 390.6 kS/s, so AM
  broadcast stations would otherwise fold down into the band) and below ~10 kHz
  (60 Hz mains harmonics).
* Outdoors, keep the antenna away from switching power supplies, LED lights and
  the house wiring, and disconnect it when there is thunder around.

`vlf_host.py level` shows the input level once a second while you set the gain
(aim for 30–300 counts RMS, zero clipping). `vlf_host.py scan` then draws the
10–50 kHz spectrum in about ten seconds and names the stations it finds.

## Build and load

1. Double-click `fpga\build_vlf_sid.bat` (about 5 minutes). Result:
   `fpga\vlf_sid\build\vlf_sid.bit`, reports in `fpga\vlf_sid\build\`.
2. Board on USB-JTAG, open the **Vivado Tcl Shell**:
   ```
   cd P:/Downloads/freq-lab/fpga/vlf_sid
   source program.tcl
   ```
   This loads RAM only; a power cycle puts the board back exactly as it was.

## Use (PC, `pip install pyserial matplotlib`)

```
python tools/vlf_host.py COM7 info            # status, sample rate, all 8 stations now
python tools/vlf_host.py COM7 level           # set the preamp gain with this
python tools/vlf_host.py COM7 scan            # 10-50 kHz spectrum, names the peaks
python tools/vlf_host.py COM7 log --goes      # 1 line per second to vlf_YYYY-MM-DD.csv (+ GOES X-rays)
python tools/vlf_host.py plot vlf_2026-10-02.csv --goes goes_2026-10-02.csv
python tools/vlf_host.py COM7 tune 7 23.4     # move channel 7 to another station
```

Default channels: NLK 24.8, NPM 21.4, NAA 24.0, NML 25.2, NAU 40.75, NWC 19.8,
JJI 22.2 kHz and a 30.0 kHz empty reference (noise and lightning).

What a flare looks like: during daylight on the signal path, a C-, M- or
X-class flare (GOES curve) is matched within minutes by a step of a few dB in
the daytime stations, then a recovery over 30–90 minutes. Sunrise and sunset
produce big, slow, daily-repeating swings; flares are the sudden ones that line
up with GOES.

## Design numbers

* XADC VAUX1, 12 bit, 390,625 S/s (50 MHz / 4 ADC clock, 32 clocks per
  conversion). The FPGA measures its own sample rate (register 1A) and the host
  tunes with the measured value; with GPS it also corrects the crystal (±50 ppm).
* Each channel: 32-bit NCO (0.09 mHz steps), 12-bit-phase sine (spurs about
  −72 dBc), 12×16 mixer, 3-stage CIC decimating 1024× (381 outputs/s), 57-bit
  registers (cannot overflow), rounded to 24-bit I/Q.
* Channel shape: −0.7 dB at ±50 Hz, −3 dB at ±100 Hz, −80 dB at ±400 Hz (the
  usual station spacing), sidelobes below −40 dB. A 200-baud MSK station reads
  0.6 dB below its full power; 400 Hz away you still see −33 dB of its own
  spectrum (that is really there, not filter leakage).
* Per window and channel: Σ(I²+Q²) and the largest single I²+Q² (lightning
  sferics), plus input RMS, DC, min/max and clipped-sample count.
* A tone of A ADC counts reads `sqrt(POW/NDEC) = A × 2047.94`.

## Verification (simulation, Icarus Verilog)

```
cd fpga/vlf_sid
python3 sim/gen_files.py
iverilog -DSIMULATION -o sim/tb_vlf sim/tb_vlf.v hdl/*.v
cd sim && vvp tb_vlf && python3 check_vlf.py
```

Stimulus: a 100-count 200-baud MSK station at 24.8 kHz, a 20-count tone at
21.4 kHz, a 300-count tone 400 Hz from the 24.0 kHz channel, ±3-count noise,
a clipping burst, and a fake GPS PPS. Results:

* testbench: 33/33 register, protocol, PPS, window and snapshot checks pass;
* every decimated I/Q value of all 8 channels is identical to a bit-exact
  Python model, and every window sum and register read matches;
* the fixed-point receiver agrees with an ideal floating-point receiver within
  0.003 dB; the 20-count tone reads 20.01; the 400 Hz-off 300-count tone is
  rejected by 80 dB; the channel response matches the CIC formula to 0.001 dB.

Vivado 2026.1 (xc7z020clg400-2, Oct 1 2026): builds in about 6 minutes, exit
code 0, 0 critical warnings. Timing met at 50 MHz: setup slack +6.3 ns, hold
+0.036 ns, 0 failing of 44,858 endpoints. 9,142 LUTs (17 %), 14,028 flip-flops
(13 %), 50 DSPs (23 %), 4.5 block-RAM tiles. Every pin placed as in the table
above at LVCMOS33. Estimated power 0.15 W, junction 26.7 °C. Not yet run on
hardware.

## Register map (UART, 115200 8N1, `R aa` / `W aa dddddddd`)

| Addr | Name | | |
|---|---|---|---|
| 00 | ID | RO | 0x564C0001 |
| 01 | CTRL | RW | bit0 RUN, bit1 PPS_MODE (default 3) |
| 02 | WIN | RW | window length in samples without PPS (default 390625) |
| 03 | STATUS | RO | 31:16 window count; bit3 PPS alive; bit2 last window timed out; bit1 last window ended on PPS; bit0 RUN. **Reading it freezes the last window into 04–0D and 20–3F.** |
| 04 | SEQ | RO | window number of the frozen copy |
| 05 | NSAMP | RO | samples in the window |
| 06 | NDEC | RO | outputs per channel in the window |
| 07 | FLAGS | RO | bit0 ended on PPS, bit1 started on PPS, bit2 timed out |
| 08 | CLIP | RO | samples at code 0 or 4095 |
| 09 | XMINMAX | RO | {max code, min code} |
| 0A/0B | SQ | RO | Σ(code−2048)², 64 bit |
| 0C/0D | SUM | RO | Σ(code−2048), signed 64 bit |
| 0E | ADC | RO | live code |
| 0F | PPS_CNT | RO | PPS edges since power-up |
| 10–17 | FTW0–7 | RW | channel frequency = FTW × fs / 2³² |
| 18 | FAN_DUTY | RW | % (default 60) |
| 19 | FAN_RPM | RO | |
| 1A | FS_CLKS | RO | 50 MHz clocks per 65536 samples (8388608 = 390625 S/s) |
| 20+4k | POW_LO(k) | RO | channel k Σ(I²+Q²) low word |
| 21+4k | POW_HI(k) | RO | high word |
| 22+4k | PMAX(k) | RO | largest I²+Q² in the window, bits 47:16 |

Replies are queued (512-byte FIFO), so a batch of reads can be sent at once;
`vlf_host.py` reads a whole window in one USB round trip.

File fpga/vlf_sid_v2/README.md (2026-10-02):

# vlf_sid_v2 — VLF solar-flare receiver + lightning time-of-arrival capture

Version 2 of [`../vlf_sid`](../vlf_sid/README.md). Everything in v1 is unchanged
(same 8 station channels, same windows, same register map, same wiring); v2 adds
a **sferic capture** block so a network of these receivers can locate lightning
by time of arrival, and the host software can upload both to `tools/sid_server.py`.

v1 stays in its own folder with its own verified bitstream. Build and load v2
from here; `vlf_host.py` recognises both (ID 0x564C0001 = v1, 0x564C0002 = v2).

## What the sferic capture does

A lightning stroke arrives at the antenna as a broadband impulse much larger
than the steady station carriers. `hdl/sferic_capture.v` watches every raw ADC
sample (390,625 S/s). When |code − 2048| reaches `SF_THRESH` it records:

* **which GPS second** (the PPS count) and **how many 50 MHz clocks** had
  passed since that second's PPS edge: a 20 ns stamp;
* a **64-sample snapshot**: 16 samples before the trigger, the trigger sample,
  47 after (2.56 µs per sample), so the host can interpolate the arrival to a
  fraction of a sample and cross-correlate stations;
* the largest |x| in the snapshot and its sign (stroke polarity).

Then it ignores triggers for `SF_HOLDOFF` samples (default 5 ms: one stroke =
one event). Up to 32 events wait in a block-RAM FIFO; triggers that arrive while
it is full are counted in `SF_LOST`. The host reads the oldest event's header
and snapshot (36 registers, one USB round trip) and pops it.

Two stations stamping the same stroke give the arrival-time difference
directly (1 µs = 300 m). The stamp is the clock at which the sample was
registered; the XADC's conversion delay is the same at every station and
cancels in the difference.

## New registers (UART, same protocol as v1)

| Addr | Name | | |
|---|---|---|---|
| 40 | SF_THRESH | RW | |code−2048| at or above this triggers; 0 = off (default 0) |
| 41 | SF_HOLDOFF | RW | samples ignored after a trigger (default 1953 = 5 ms) |
| 42 | SF_COUNT | RO | events captured since power-up |
| 43 | SF_NEV | RO | events waiting (0..32) |
| 44 | SF_POP | RO | reading it drops the oldest event; returns SF_NEV before the drop |
| 45 | EV_PPS | RO | oldest event: PPS count at the trigger |
| 46 | EV_CLK | RO | bit 31 = a PPS had been seen; [25:0] clocks since that PPS (20 ns each) |
| 47 | EV_INFO | RO | {pre-trigger samples = 16, length = 64, 3'b0, polarity (1 = negative), |peak| (12 bit)} |
| 48 | EV_SEQ | RO | event number |
| 49 | SF_LOST | RO | triggers dropped because the FIFO was full |
| 60–7F | EV_SNAP | RO | 64 raw codes, two per word {4'b0, s[2k+1], 4'b0, s[2k]}; s[16] is the trigger sample |

ID reads 0x564C0002. Registers 00–3F are exactly v1's.

## Use

```
fpga\build_vlf_sid_v2.bat                         Vivado build (about 6 minutes)
   Vivado Tcl shell:  cd P:/Downloads/freq-lab/fpga/vlf_sid_v2 ; source program.tcl

python tools/vlf_host.py COM7 info                shows v2 and the capture state
python tools/vlf_host.py COM7 level               set the preamp gain as before
python tools/vlf_host.py COM7 sferics --thresh 600
       one line per stroke: UTC time to the microsecond, 20 ns clock, polarity, |peak|;
       CSV with the 64-sample snapshot; add --station NAME --push http://server:8750
       to feed the network server (tools/sid_server.py)
python tools/vlf_host.py COM7 log --station NAME --push http://server:8750
       the usual 1-s station log, uploaded as well
```

Choosing the threshold: run `level` and note the input RMS; the station carriers
sum to a few hundred counts peak. Set `--thresh` 2–3× the peak of the quiet
signal (600 is right for an RMS around 120). Near strokes exceed 1000 counts;
the clipping LED tells you the gain is too high.

Absolute time: the host maps the board's PPS count to UTC using the PC clock
(must be within ±0.5 s, e.g. NTP). Inside the second the stamp is the GPS PPS
plus the 20 ns clock count, independent of the PC.

## Verification

Simulation (`sim/`, Icarus Verilog; Python checker needs numpy):

```
cd fpga/vlf_sid_v2 && python3 sim/gen_files.py
iverilog -DSIMULATION -o sim/tb_vlf sim/tb_vlf.v hdl/*.v && cd sim && vvp tb_vlf && python3 check_vlf.py
```

The stimulus is v1's (MSK station, tones, noise, clip burst) plus two synthetic
strokes: damped 8 kHz oscillations of 1400 counts, positive-first at sample
45000 and negative-first at 75000. The clipping burst at sample 50000 is a
third, legitimate trigger (|peak| = 2048, negative).

* testbench: **59/59** checks — all 33 of v1's, the new register defaults and
  write/readback, three events read over the UART with the right GPS second,
  PPS-seen flag, PRE/LEN, polarity, the 2048 clip peak, sequence numbers, FIFO
  counts before and after each pop, pop on an empty FIFO;
* `check_vlf.py`: **19/19** — all 16 of v1's (bit-exact DDC, windows, registers,
  physics) plus: triggers at exactly the samples the threshold/hold-off rule
  predicts (45007, 50000, 75002), and for every event the GPS second, the
  20 ns clock count (exact), polarity, |peak|, SEQ and all 64 snapshot samples
  equal to the stimulus and the logged PPS/trigger times.

Vivado 2026.1 (xc7z020clg400-2, Oct 1 2026): exit code 0, **0 critical
warnings**, all timing constraints met at 50 MHz (setup slack +4.46 ns, hold
+0.031 ns, 0 failing of 46,642 endpoints). 9,535 LUTs (17.9 %), 14,561
flip-flops (13.7 %), 50 DSPs, 7.5 block-RAM tiles (5.4 %). All 11 pins placed
as constrained (A20 uart_rx, B19 uart_tx, C20 gps_pps, E17/D18 antenna, G14 key,
H16/H17 fan, R19/V13 LEDs, U18 clock). 0.155 W, junction 26.8 °C. Not yet run
on hardware.

Host software: `tools/test/test_vlf_host.py` runs `vlf_host.py` against a
software model of this register file (`tools/test/fake_vlf_board.py`) and a
stub server: **16/16** — both IDs accepted, `log --push` rows delivered with
the right station and levels, three injected strokes logged with raw stamps
within 20 ns of the injected times, polarity, peak, snapshot and sub-sample
refinement, uploads, and queued delivery through a server outage.

## Files

| File | |
|---|---|
| `hdl/sferic_capture.v` | the new block (trigger, 20 ns stamps, snapshot RAM, FIFO, read port) |
| `hdl/vlf_top.v`, `hdl/cmd_regs_vlf.v` | v1's with the block instantiated and the registers above |
| `hdl/*` others, `constraints/vlf_jm1.xdc` | unchanged from v1 |
| `sim/gen_files.py` | v1's stimulus + the two strokes |
| `sim/tb_vlf.v`, `sim/check_vlf.py` | v1's checks + the event checks |
| `build.tcl`, `program.tcl`, `../build_vlf_sid_v2.bat` | build and load; output `build/vlf_sid_v2.bit` |

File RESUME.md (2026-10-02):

# Preston E
prestonericson7@gmail.com · github.com/prestonericson7-lang

**Embedded Systems / FPGA / Instrumentation Engineer** — self-taught builder who ships verified hardware-software systems end to end: Verilog on Zynq-7020 FPGAs, real-time firmware on Teensy 4.1 / ESP32 / STM32, Python data pipelines and servers, and the test harnesses that prove each one works before it touches hardware.

## Core Skills
FPGA: Verilog-2005, Xilinx Vivado 2026.1 (synthesis, place-and-route, timing closure, XADC, DSP48, block RAM), Icarus Verilog testbenches, bit-exact Python reference models · Embedded: C/C++ on Teensy 4.1 (ARM Cortex-M7, CMSIS-DSP), ESP32 / ESP32-S3, STM32F1/F4/H7, Arduino-CLI and PlatformIO, SPI/I2C/UART, GPS PPS timing, RadioLib (SX1262, CC1101) · DSP: digital down-conversion, NCO + CIC decimation, lock-in detection, cross-correlation, FFT/Welch spectra, IIR notch/Butterworth design, sub-sample time-of-arrival · Software: Python 3 (numpy, scipy, pyserial, matplotlib, sqlite3, http.server), JavaScript/HTML5 canvas, Git · Domains: VLF/ELF radio, space-weather instrumentation, SDR (RTL-SDR, rtl_power), sensor fusion (MPU-6050, fluxgate, EEG front ends), game engines (Unreal Engine 5.7 C++, Unity 6)

## Projects

### freq-lab — Open Instrumentation Stack for Space-Weather and Low-Frequency Measurement (2026)
Zynq-7020 FPGA + Teensy 4.1 + Python. Receivers, loggers, a station network server and kit documentation, built as a product line.
- Designed an 8-channel VLF solar-flare (SID) receiver in Verilog: on-chip 12-bit ADC at 390,625 S/s, eight 32-bit NCO + 3-stage CIC digital down-converters (1024× decimation, −80 dB rejection 400 Hz off-channel), GPS-second windowing; Vivado build meets 50 MHz timing (WNS +6.3 ns), 17% LUTs, 50 DSPs, 0 critical warnings.
- Verified it to the bit: 33/33 Verilog testbench checks and every decimated I/Q sample of all 8 channels identical to an independent Python integer model; fixed-point receiver within 0.003 dB of an ideal floating-point receiver.
- Added lightning time-of-arrival capture (v2): threshold trigger, 20 ns GPS-relative timestamps, 32-event FIFO with 64-sample pre/post-trigger snapshots in block RAM; 59/59 testbench and 19/19 model checks, timestamps exact to the clock, timing met (WNS +4.5 ns) in a single build.
- Found and fixed a latent testbench bug (hex replies beginning with "E" misread as errors) by logging the UART byte stream; re-verified the baseline design before touching it.
- Wrote the station host software: batched register reads (one USB round trip per second), GPS-corrected sample clock (±50 ppm crystal trimmed against PPS), NOAA GOES X-ray feed integration, sub-sample arrival refinement, resilient HTTP uploader with queue-and-retry (verified through a simulated server outage); 16/16 tests against a software model of the board.
- Built a solar-flare detector with a trend-following baseline (two half-window medians, linear extrapolation) and 20-second mean onset confirmation: on a synthetic day with 9 dB sunrise/sunset ramps, 200 lightning spikes and two flares (+3.2 dB, −2.0 dB), detects both within 90 s of onset with 0 false alarms; 14/14 checks including GOES confirmation and multi-station correlation.
- Built a stdlib-only central server (SQLite, JSON API, background detector, GOES fetcher, cross-station stroke matching to 3 ms) and a dependency-free live dashboard (HTML5 canvas, auto-refresh, 1 h–3 d ranges, alert and time-of-arrival tables); 20/20 end-to-end tests: 21,600 rows from two stations, a stroke matched across stations to 1,200 µs, GOES-confirmed multi-station alerts with no duplicates, malformed input refused.
- Wrote an RTL-SDR riometer / solar-burst logger (band power with narrowband-interferer rejection, sidereal-day quiet curve as a 7-day upper quartile): on 3 synthetic sidereal days a 2.5 dB absorption event read 2.56 dB and the quiet baseline held within 0.25 dB; 8/8 tests.
- Documented the product line as sellable kits (antenna + preamp design and BOM, acceptance test, network setup, pricing tiers) with the limits stated plainly.
- RF survey meter on Teensy 4.1 + AD8318 log detector: 50 kS/s sampling, power-mean dBm and µW/cm² from antenna aperture, two envelope spectra (0.06–125 Hz, 12 Hz–25 kHz) with a modulation-line identifier (Wi-Fi beacon 9.77 Hz, LTE, DECT, Bluetooth), a hysteresis pulse detector with a 120-bin log interval histogram, two-point calibration and GPS-tagged survey rows; analysis kept Arduino-free and PC-tested (18/18 on a synthetic Wi-Fi + LTE waveform: 97 beacon intervals recovered for 98 beacons), host tool 7/7, compiles at 102 KB.
- Schumann-resonance product pair: a Teensy 4.1 + ADS1256 24-bit two-channel ELF monitor (H and E multiplexed at 1,000 SPS each, mains notches, 4,096-point Welch spectra, five cavity modes tracked with parabolic centre-frequency interpolation, E/H wave impedance with coherence, GPS stamps, JSON reports; compiles at 105 KB) and an ESP32 calibrated field generator (8 kS/s five-tone synthesis, coil current sensed and converted to microtesla from coil geometry, closed-loop field target, SHA-256-committed blinded sham sessions from the hardware RNG, magnetophosphene threshold mode, phone web page; compiles for ESP32 and ESP32-S3), plus a host tool (6/6 tests) and a kit document with a noise budget (0.25 pT/√Hz floor for a 30,000-turn rod coil).
- Earlier freq-lab designs, all Vivado-built and simulated end to end: digital lock-in amplifier with resonance tracker (amplitude within 0.1%, phase within 0.4°), two-detector photon coincidence counter (12/12 checks, ±20 ns window), two-channel cross-correlator with GPS PPS stamping (7/7 checks); Teensy firmware for swept-sine resonance measurement (f0 to 0.03%, Q exact on a simulated resonator), six-sensor vibration/transfer-function logger, ELF 0.25–45 Hz spectrum logger with mains rejection (2 µV line read 1.4135 µV rms of 1.4144 under 1 V of mains), binaural-beat generator with blinded sessions, randomized-trial strobe driver with hardware RNG and safety interlock, sub-GHz CC1101 spectrum scanner, and an STM32 + SX1262 swept RF insertion-loss probe.

- Designed a ring-oscillator true random number generator in Verilog with the NIST SP 800-90B health tests (Repetition Count and Adaptive Proportion) in hardware, von Neumann debiasing and LFSR conditioning: output is withheld while a health test is tripped, and on-chip temperature is logged. Verified the entire deterministic pipeline bit-exactly against an independent Python model across balanced, stuck and biased streams (42 checks) using a simulation backdoor for the un-simulatable oscillators; Vivado build meets timing (WNS +12.6 ns), 570 LUTs, 0 critical warnings; host tool with a statistical self-test passes 14/14.
- Built a closed-loop slow-oscillation sleep-cueing system (Teensy 4.1 + EEG): a deep-sleep stage gate, a slow-oscillation trough detector with filter-delay compensation (cues land within 8 ms of target), refractory/rate/arousal gating, a SHA-256-sealed word-pair split and blinded stim/sham nights with a permutation-test scorer; signal processing PC-tested 22/22 on synthetic EEG.
- Wrote reusable experiment-integrity tooling: a blind-randomization harness with pre-posted SHA-256 commitments and an order-independent permutation test, a nuisance-channel veto that flags when a signal is explained by vibration/mains/field/sound via windowed correlation, and a seizure-safety gate for flicker stimulation (ramp-in, brightness cap, frequency-band screen, hardware abort) — each PC-tested to zero failures.
- Red-team pass over all of the above found and fixed real defects: a permutation p-value inverted by condition-label order, a continuous-mains contamination the veto missed, an EEG high-pass that cut a 100 µV slow wave to 39 µV, and a UART test reader that misparsed hex values starting with "E".

### Large-Scale Document Mining (2026)
- Built a parallel PDF-to-text pipeline over 12,301 declassified documents (6.6 GB) and extracted 2,206 frequency- and field-measurement statements with a unit-aware regex ranker — the source material for the VLF, ELF and RF instrument designs above.

### NeuroRuins — Unreal Engine 5.7 C++ Survival Game with a Shared Neural AI (2026)
- Architected "one shared brain, individual minds": a single learned model serving every AI character with per-agent memory, personality and needs; project documented (vision, roadmap, class map) and compiling against UE 5.7.4.

### Coldreach — UE 5.7 C++ Survival-Extraction Framework (2026)
- Compile-verified gameplay framework (inventory, extraction loop, damage/medical, networking scaffolding) built as a reusable base for DayZ/Tarkov-style projects.

### Vehicle Diagnostics and In-Car Monitoring (2026)
- merc-diag: OBD/CAN scanner plus camshaft/crankshaft oscilloscope for a 2010 Mercedes W212 on STM32H743 + Teensy 4.1 + ESP32; all four firmware targets compile-verified.
- Car-Sentinel: in-car monitor/logger/controller for a 2017 BMW 330e (Orange Pi + ESP32-P4 + Teensy + ESP32-S3 + FPGA option); foundation built and verified.

### Autonomous Agents and Local AI (2026)
- OMEGA_AI: multi-agent "council" system on Python 3.14 with Groq inference, brought from broken venv to live operation.
- All Things Human: offline survival-knowledge assistant with portable SQLite + embeddings RAG over local Ollama models and a 35-role reasoning council (v0.9 online).
- StonksAi: Kalshi whale-flow trading agent with verified credentials and paper-capital risk limits.

### Other Builds
- Torsion pendulum test rig: 3D-printed sealed rotor, ESP32-S3 camera tracker (0.1–0.2 mrad/frame), hash-chained blinded session log, 5% false-alarm rate on 200 simulated null sessions.
- Living Garden (Unity 6 artificial-life sim with shareable creature genomes); Mining Around (Unity 6 / UE 5.7 tycoon); PZ7020 FPGA as a GPU for Orange Pi 4 Pro; ESP32 ESP-NOW sensor-node network (Kodi); Teensy/ESP32 vehicle and lab instruments.

## Tools and Environments
Vivado 2026.1 · Icarus Verilog 11 · Arduino-CLI (Teensy 1.62, ESP32 3.3, STM32 3.0 cores) · PlatformIO · Python 3.14 · WSL Ubuntu 22.04 · Git · Unreal Engine 5.7.4 · Unity 6 · KiCad-level schematic reading, datasheet-driven pin mapping

## Education and Self-Directed Training
Self-taught through shipped projects (DayZ modding → engine C++ → embedded → FPGA); [add any formal education, certifications, or coursework]

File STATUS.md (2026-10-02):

# freq-lab — verified status

Re-verify everything in one command:

```
python run_all_tests.py          # Python + C++ + FPGA sims
python run_all_tests.py --quick  # skip the FPGA sims (faster)
python run_all_tests.py --full   # also the slow v1 vlf_sid sim
```

Last full run: **21 test groups, 343 checks, ALL GREEN.** A sim that times out
under heavy machine load (e.g. a Vivado build running) is reported `SLOW`
(inconclusive), not a failure — re-run it alone when the machine is idle.

## What is verified

| Area | How | Result |
|---|---|---|
| 12 Python host/server/analysis tools | `tools/test/test_*.py` | 137 checks, 0 fail |
| End-to-end station chain (real clients → real server → detector → API) | `tools/test/test_station_e2e.py` | 10, 0 fail |
| 6 Arduino signal-processing / safety cores | `teensy/*/test/pc_test*.cpp` (g++) | 85 checks, 0 fail |
| `fpga/vlf_sid_v2` (VLF + lightning TOA) | iverilog testbench + Python bit-exact model | 59 + 19, 0 fail |
| `fpga/trng` (ring-osc + SP 800-90B) | iverilog + bit-exact model (balanced/stuck/biased) | 9 + 33, 0 fail |
| `fpga/vlf_sid` v1, lockin, photon, correlator | iverilog (verified earlier; v1 re-confirmed 33+16) | 0 fail |
| All Teensy / ESP32 / STM32 sketches | arduino-cli compile | all compile |
| `fpga/vlf_sid_v2`, `fpga/trng` bitstreams | Vivado 2026.1 batch build | built, timing met, 0 critical warnings |

## Build artifacts (ready to load)

| Bitstream | Timing | Resources | Notes |
|---|---|---|---|
| `fpga/vlf_sid_v2/build/vlf_sid_v2.bit` | WNS +4.5 ns @ 50 MHz | 17.9 % LUTs, 50 DSP | `program.tcl` loads it (RAM only) |
| `fpga/trng/build/trng.bit` | WNS +12.6 ns @ 50 MHz | 1.1 % LUTs | 16 ring-osc loops flagged allowed |

Earlier builds (lockin, photon_counter, correlator, vlf_sid v1) are in their
own `build/` folders.

## The VLF SID station

FPGA (PZ7020) + Teensy 4.1 GPS-aware bridge + ESP32-32E (spare) + RTL-SDR +
GPS/PPS. Full wiring and run sequence: **`docs/station-setup.md`**.
- Receiver: `fpga/vlf_sid_v2` (built). Load with its `program.tcl` (RAM only, so
  it does not disturb the GPU matrix-math config — power-cycle restores it).
- Bridge: `teensy/vlf_station/vlf_station.ino` (compiles; NMEA parser 11/11).
- Host: `tools/vlf_host.py --gps-bridge` stamps windows with true GPS time (21/21).
- SDR complement: `tools/riometer_host.py` (30 MHz absorption; the SDR can't do VLF).
- Dashboard + alerts: `tools/sid_server.py` + `dashboard/index.html` (20/20, e2e 10/10).

## What is NOT done (needs real hardware)

1. **Nothing has run on hardware yet.** Everything above is compile-, simulation-
   or model-verified. The first power-on follows the run sequence in
   `docs/station-setup.md`, now with the Teensy GPS bridge in the loop.
2. **The VLF loop antenna + preamp** (1 m loop, ~60 dB preamp, 10–50 kHz) feeding
   the FPGA JM1-6/8 is not built — the receiver can't hear the Navy stations
   without it. Design: `docs/analog-front-ends.md`.
3. The analog front ends in `docs/analog-front-ends.md` (VLF loop, Schumann coil,
   RF detector, photon SiPM) are designed from a noise budget but not yet built.

## Documentation

- `README.md` — overview and first-run.
- `WIRING.md` — every pin, every board, with diagrams.
- `docs/station-setup.md` — the full VLF SID receiver station.
- `docs/analog-front-ends.md` — the analog front-end designs.
- `fpga/*/README.md` — each FPGA design, its register map and its verification.
- `RESUME.md` — background.

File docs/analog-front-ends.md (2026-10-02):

# Analog front-end designs

The firmware and FPGA designs in this repo assume a signal already conditioned
to the converter's input range. This note gives the analog front ends that do
that conditioning — the part that lives between the physical sensor and the pin.
All are designed from first principles (noise budget, bandwidth, dynamic range);
none has been built and measured yet.

- [VLF loop antenna + preamp (for the SID receiver)](#vlf-loop-antenna--preamp)
- [Schumann / ELF induction coil, preamp and ball antenna](#schumann--elf-front-end)
- [Broadband RF power detector (AD8318)](#broadband-rf-power-detector)
- [Photon detector front end (SiPM)](#photon-detector-front-end)

---

## VLF loop antenna + preamp

Feeds `fpga/vlf_sid` / `vlf_sid_v2` on JM1-6/8. The on-chip ADC wants 0–1.0 V
centred at 0.5 V, 10–50 kHz.

```
loop (1 m square, 10 turns)  ->  preamp  ->  0.5 V bias + 100 Ω  ->  JM1-6
                                            2.2 nF to JM1-8 (ground)
```

**Loop.** 1 m × 1 m square frame, **10 turns** of 22–26 AWG magnet wire (~40 m).
Inductance ~0.4 mH, self-resonant well above 100 kHz. A loop responds to the
magnetic field, so it rejects most of a building's electric-field noise; it is
directional (edge-on to the station is loudest, face-on is a null). Site it
outdoors or in an attic, away from switching supplies and house wiring. Strong
Navy stations (NAA, NLK at ~1000 km) induce ~0.1–1 mV across 10 turns; weak ones
~10 µV. The preamp must bring 10 µV–1 mV to 30–300 ADC counts (7–75 mV) without
clipping on a nearby lightning stroke.

**Preamp (two stages, single 3.3 V from JM1-2).**
1. *Input stage* — low-noise op-amp (OPA1612 / LT6202) as an instrumentation
   input across the loop, gain 20; 10 kΩ across the loop damps its resonance.
   Input-referred noise under 2 nV/√Hz.
2. *Band-pass* — 2nd-order high-pass at 8 kHz (rejects 60 Hz harmonics and
   supply hash) and 2nd-order low-pass at **60 kHz**. The low-pass is mandatory:
   the ADC samples at 390.6 kS/s, so AM broadcast (530 kHz+) would alias into
   the band without it.
3. *Output stage* — gain 10–50 (trimmer; `vlf_host.py level` sets it), biased to
   0.5 V, 100 Ω series + 2.2 nF to ground at the pin. Running it from the FPGA's
   3.3 V rail means it physically cannot exceed 3.3 V; the ADC reads full scale
   above 1.0 V and the clip LED shows it.
4. Total gain ~60 dB, adjustable 40–70 dB.

**GPS.** Any 3.3 V module with a PPS output (u-blox NEO-6M/M8N). PPS → JM1-18;
the FPGA needs only the PPS. With the `vlf_station` Teensy bridge the NMEA stream
gives true UTC as well.

---

## Schumann / ELF front end

Feeds `teensy/schumann_monitor` (ADS1256, 24-bit). Two channels — magnetic (H)
and electric (E) — so the monitor can report the Earth–ionosphere cavity's wave
impedance, not just amplitude.

### Induction coil (H channel)

Signal: the Schumann fundamental is ~1 pT/√Hz. An air/ferrite coil gives
V = 2π f N A B. To get 1 pT at 7.8 Hz above a ~1 nV/√Hz preamp, the coil needs
N·A ≳ 50e-9 / (2π·7.8·1e-12) ≈ 1000 turn·m².

| Design | Turns | Core | N·A | V per pT @ 7.8 Hz | R | Notes |
|---|---|---|---|---|---|---|
| Rod coil | 30,000 × 36 AWG | 60 cm × 10 mm ferrite/mu-metal rod, µ_eff ≈ 200 (A_eff ≈ 1.6e-2 m²) | 470 | 23 nV | ~2 kΩ | observatory style, ~70 cm, ~1.5 kg |
| Air loop | 400 × 24 AWG | 2 m × 2 m frame, A = 4 m² | 1600 | 78 nV | ~60 Ω | needs a yard; cheap |

Noise budget (rod coil): thermal √(4kTR) = 5.8 nV/√Hz at 2 kΩ dominates the
1 nV preamp, so the floor is 5.8 / 23 = **0.25 pT/√Hz**. The 1 pT fundamental
stands 12 dB above it; modes 2–3 clear it; 4–5 are marginal. Lower resistance
(thicker wire / bigger rod) buys floor. The `floor30_pT` column reports the
measured floor so it can be checked against this budget.

Winding: split bobbin (two halves) to halve self-capacitance; keep the
self-resonance above 100 Hz (30 k turns on a rod resonate ~300–600 Hz). A slit
copper-foil electrostatic shield tied to the preamp ground (a closed wrap is a
shorted turn).

### Preamp (H)

Low-noise instrumentation front end: AD8421 (3 nV/√Hz) or a paralleled chopper
pair OPA2188/ADA4522 (5.8 nV each → 4 nV paired, no 1/f). Gain 1000 (32 × 32),
1st-order high-pass at 0.3 Hz, 2nd-order low-pass at 100 Hz, output biased at
2.5 V for the ADS1256. 1 pT → 23 nV → 23 µV at the ADC; at PGA 8 that is ~300
codes, noise ~70 codes rms over the band. Battery supply; preamp at the coil,
ADC board at the Teensy, shielded twisted pair between.

### Ball antenna (E channel)

Schumann E-field ~0.3 mV/m at the fundamental. A 20 cm sphere on a 2 m insulated
mast picks up E × h_eff (h_eff ≈ 1 m) → ~300 µV. An electrometer buffer (LMC6001
or ADA4530-1, 10¹⁴ Ω input, unity gain) with a 10 GΩ bias resistor; the sphere
capacitance (~10 pF) and 10 GΩ give a 1.6 Hz corner — fine for 7.8 Hz, calibrate
the roll-off with `ecal`. Dry insulator (PTFE); rain kills the E channel.

The two channels together give E/H at each resonance (the cavity's wave
impedance), and the coherence tells whether both sensors see the real field or
local noise (coherence > 0.5 = real).

---

## Broadband RF power detector

Feeds `teensy/rf_survey` on A0. An AD8318 logarithmic detector (1 MHz–8 GHz)
outputs a DC voltage proportional to input power in dB (~−24.4 mV/dB, −60 to
0 dBm).

```
AD8318 module: VCC 5 V, GND, VOUT -> 10 kΩ -> Teensy A0, 10 nF A0->GND
antenna / band filter -> AD8318 RF input (SMA)
```

Calibrate with two known levels ≥ 20 dB apart (`cal <dBm>` twice); the firmware
fits slope and intercept. `ant <GHz> <dBi>` sets the antenna aperture so the
reading converts to µW/cm² (A_eff = G·λ²/4π). A band-select filter or horn in
front chooses what the detector integrates — it cannot separate frequencies by
itself.

---

## Photon detector front end

Feeds `fpga/photon_counter` on JM1-6/8 (two channels). Each channel is a
single-photon avalanche detector (SiPM, e.g. MicroFC-10035) plus a fast
comparator producing a 3.3 V rising edge per photon. In a light-tight, cooled
enclosure the dark-count rate falls; the FPGA's coincidence window and
accidental-rate subtraction then separate correlated photons from independent
dark counts. With 1000 dark cps per channel and a 100 ns window the accidental
coincidence rate is 2·100e-9·1000·1000 = 0.0002 cps, so any coincidence rate far
above that is a real correlated source.

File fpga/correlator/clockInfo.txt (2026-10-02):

-------------------------------------
| Tool Version : Vivado v.2026.1
| Date         : Wed Sep 30 23:36:59 2026
| Host         : boobieJuicer9000
| Design       : design_1
| Device       : xc7z020-clg400-2--
-------------------------------------

For more information on clockInfo.txt clock routing debug file see https://support.xilinx.com/s/article/000035660?language=en_US

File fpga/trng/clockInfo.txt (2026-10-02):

-------------------------------------
| Tool Version : Vivado v.2026.1
| Date         : Thu Oct  1 20:20:27 2026
| Host         : boobieJuicer9000
| Design       : design_1
| Device       : xc7z020-clg400-2--
-------------------------------------

For more information on clockInfo.txt clock routing debug file see https://support.xilinx.com/s/article/000035660?language=en_US

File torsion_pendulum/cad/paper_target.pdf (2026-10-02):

squares line up
with the lid's arrow

cut on the dashed circle (95 mm); glue-stick it to the base's floor, squares along the arrow

squares line up
with the lid's arrow

cut on the dashed circle (95 mm); glue-stick it to the base's floor, squares along the arrow

50 mm - measure this; if it is not 50 mm, print again at 100 % / Actual size

## Torsion pendulum paper target (freq-lab #2)

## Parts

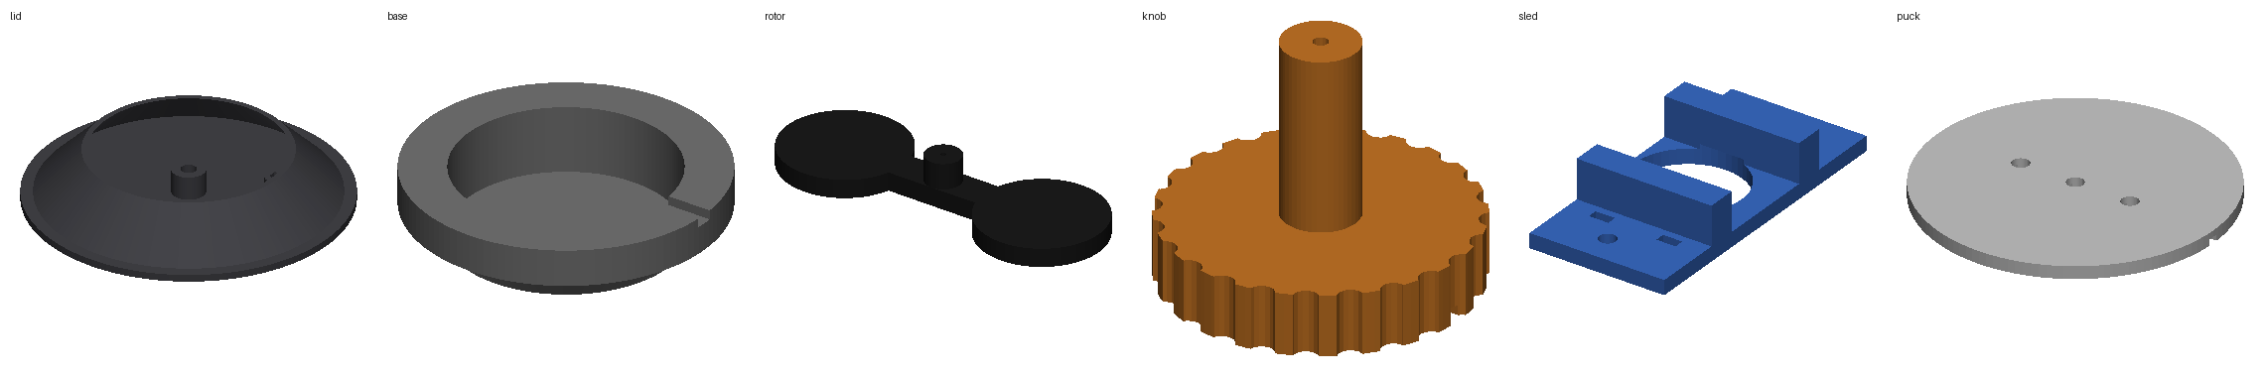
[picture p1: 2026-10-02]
torsion_pendulum/cad/parts_print_orientation.png

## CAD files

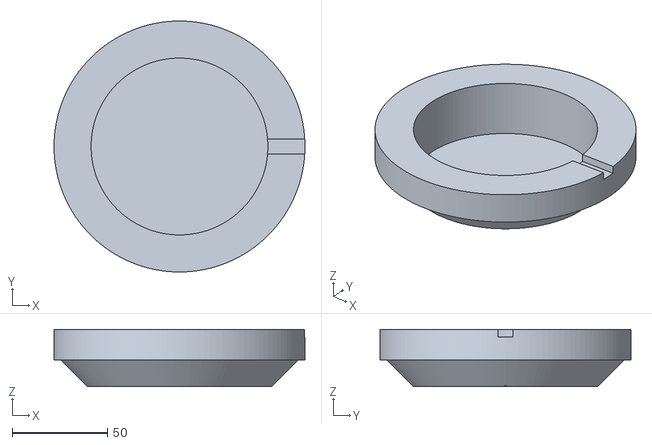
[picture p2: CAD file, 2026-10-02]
torsion_pendulum/cad/base.stl
132.0 x 132.0 x 30.0

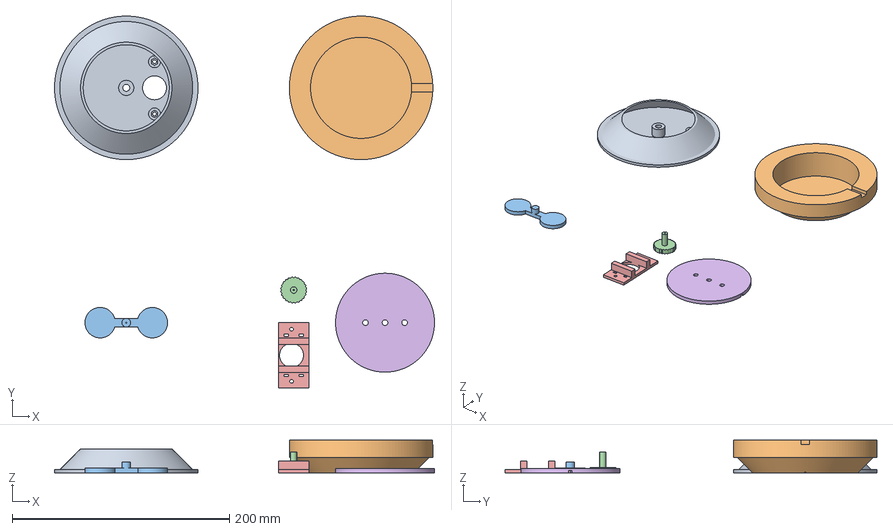
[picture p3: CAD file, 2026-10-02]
torsion_pendulum/cad/torsion_pendulum.3mf
349.5 x 342.0 x 30.0 mm
Lid (prints top-down, cone up)
Base (prints floor-down, well open above)
Rotor (2 quarters, pause at 3.4 mm)
Torsion knob + pin
Camera sled
LED puck

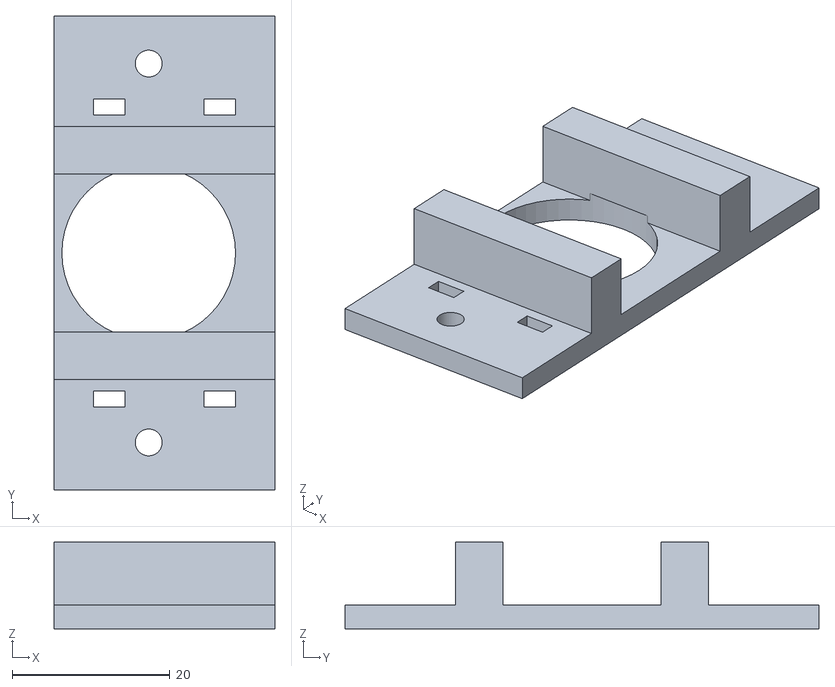
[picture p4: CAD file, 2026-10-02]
torsion_pendulum/cad/sled.stl
28.0 x 60.0 x 11.0

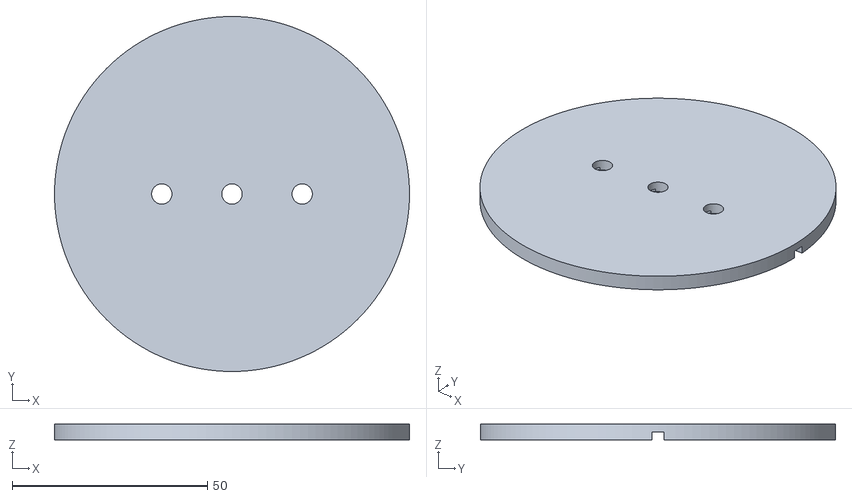
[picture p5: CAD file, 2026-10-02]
torsion_pendulum/cad/puck.stl
91.0 x 91.0 x 4.00

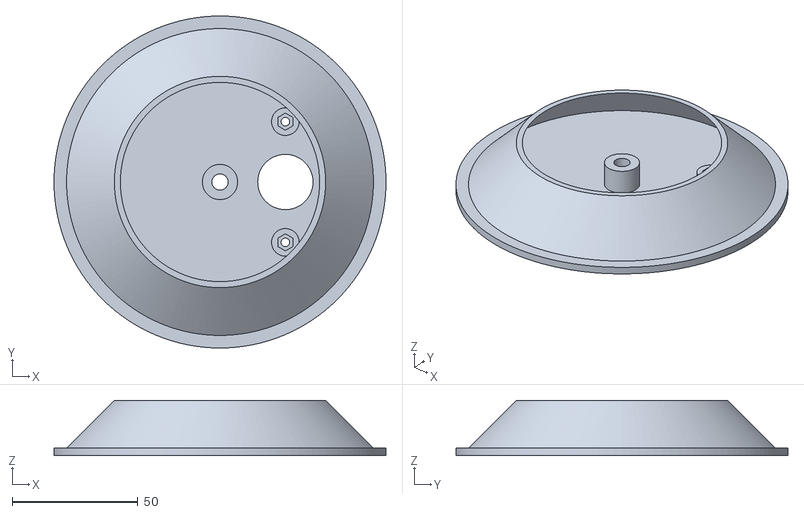
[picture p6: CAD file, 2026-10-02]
torsion_pendulum/cad/lid.stl
132.0 x 132.0 x 22.0

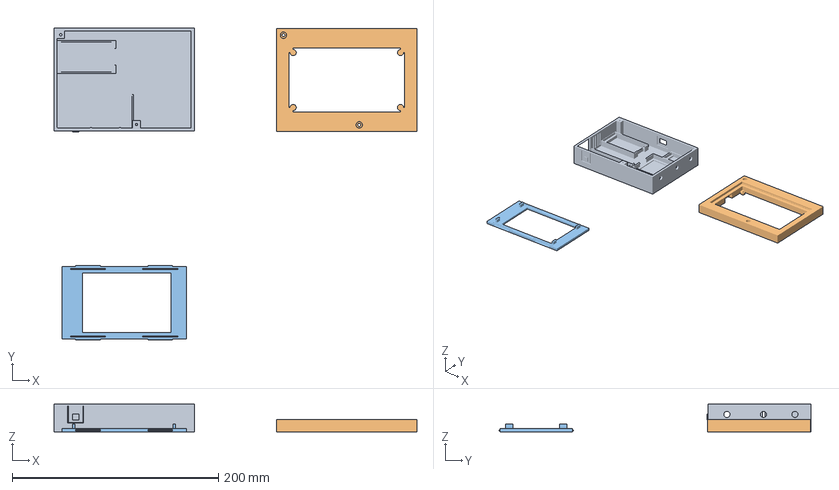
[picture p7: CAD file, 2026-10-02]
torsion_pendulum/cad/template_bambu.3mf
352.0 x 302.4 x 27.0 mm
body_v15
lid_v15
bezel_roof_lid_4inch

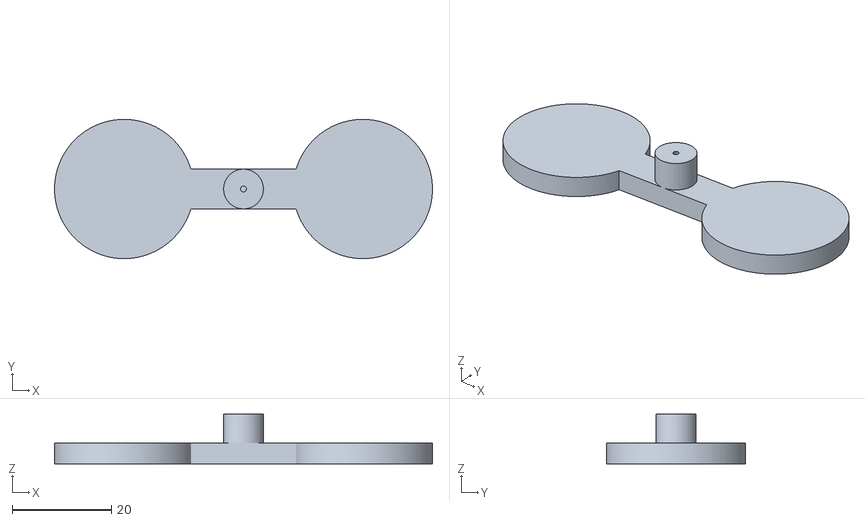
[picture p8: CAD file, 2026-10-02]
torsion_pendulum/cad/rotor.stl
76.0 x 28.0 x 10.0

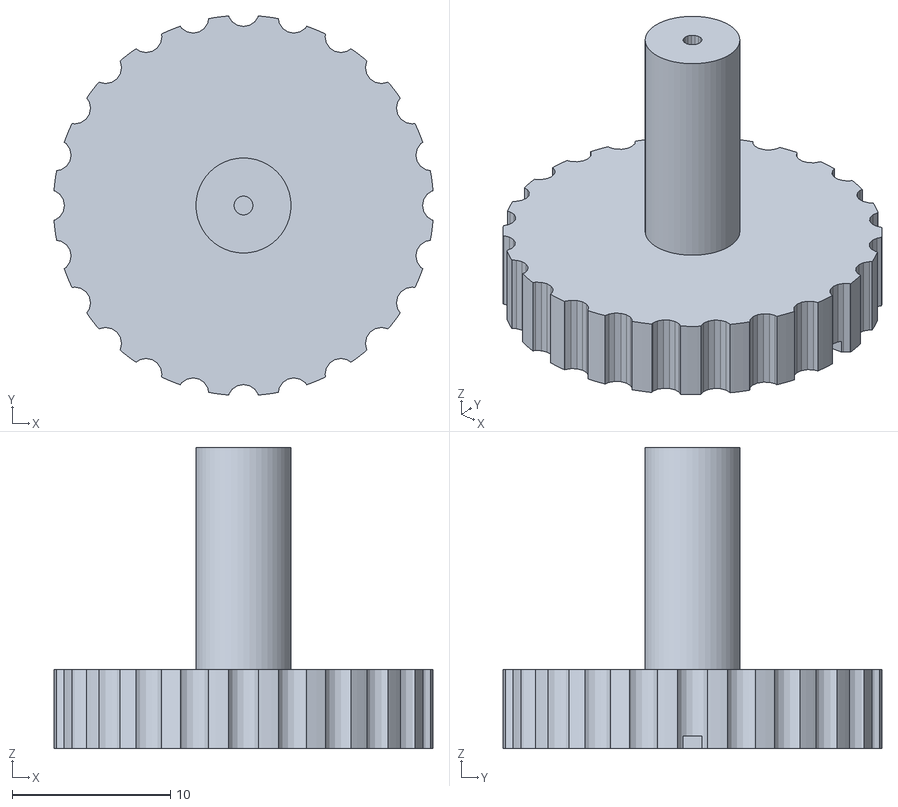
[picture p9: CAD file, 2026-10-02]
torsion_pendulum/cad/knob.stl
23.9 x 23.9 x 19.0

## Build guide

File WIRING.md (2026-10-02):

# freq-lab wiring reference

Every pin for every board, pulled from the Vivado constraint files
(`fpga/*/constraints/*.xdc`) and the sketch headers. All logic is **3.3 V**.
Common ground everywhere. Safety warnings (seizure flicker, kilovolt Kirlian
rig, on-body currents) are in each sketch's own header comment — read those
before powering anything on a person.

- [PZ7020-StarLite FPGA — JM1 header](#pz7020-starlite-fpga--jm1-header)
- [FPGA designs: what each one uses on JM1](#fpga-designs-what-each-one-uses-on-jm1)
- [Teensy 4.1 sketches](#teensy-41-sketches)
- [ESP32 Schumann generator](#esp32-schumann-generator)
- [STM32 + SX1262 RF resonance probe](#stm32--sx1262-rf-resonance-probe)
- [Full VLF SID station (FPGA + Teensy + GPS + SDR)](#full-vlf-sid-station)

---

## PZ7020-StarLite FPGA — JM1 header

Board: Puzhi PZ7020-StarLite, Zynq **xc7z020clg400-2**. JM1 is the 3.3 V
expansion header (BANK35/34). Every freq-lab FPGA design uses the same pins for
power, clock, UART, fan and LEDs; only the signal pins (6/8/9/10/11/12) differ.

| JM1 pin | FPGA ball | Signal (common) | Direction | Notes |
|---|---|---|---|---|
| 2 | — | 3.3 V | power out | powers an external preamp's output stage |
| 4 | — | GND | — | common ground |
| 5 | H16 | fan PWM | out | drives a 4-wire fan's PWM input |
| 7 | H17 | fan TACH | in | fan tach, needs pull-up (enabled in RTL) |
| 14 | B19 | UART TX | out | → USB-serial adapter RX (or Teensy RX1) |
| 16 | A20 | UART RX | in | ← USB-serial adapter TX (or Teensy TX1) |
| 18 | C20 | GPS 1PPS | in | 3.3 V 1PPS, pulled down (reads "no GPS" if open) |
| — | U18 | 50 MHz clock | in | on-board oscillator |
| — | R19 | LED1 (heartbeat) | out | 1 Hz = fabric running |
| — | V13 | LED2 (activity) | out | per-design meaning |
| — | G14 | KEY1 | in | active-low, held = fan 100 % |

Signal pins that differ per design (all 0–1.0 V max on the XADC analog pins):

| JM1 pin | FPGA ball | Used by | Signal |
|---|---|---|---|
| 6 | E17 | lockin, photon, correlator, vlf_sid(+v2) | ADC+ / ANTENNA+ / detector A (VAUX1P) |
| 8 | D18 | same | ADC− / ANTENNA− / detector B ground (VAUX1N) |
| 9 | E18 | correlator | ADC B+ (VAUX9P) |
| 11 | E19 | correlator | ADC B− (VAUX9N) |
| 10 | F16 | lockin | sigma-delta drive out (needs RC low-pass) |
| 10 | — | photon_counter | `gate` (counting enable, tie 3.3 V for always-on) |
| 12 | F17 | lockin | sync out (square wave at the drive frequency) |

`trng` uses no analog pins (its XADC reads the on-chip temperature only).

```mermaid
flowchart LR
  PC["PC (USB)"] <-->|3.3V serial| ADP["USB-serial adapter"]
  ADP -->|TX→RX| P14["JM1-14 FPGA TX"]
  ADP <--|RX←TX| P16["JM1-16 FPGA RX"]
  GPS["GPS module"] -->|1PPS| P18["JM1-18 (C20)"]
  SENS["sensor / antenna preamp<br/>0..1.0 V"] -->|signal| P6["JM1-6 (E17)"]
  SENS -->|ground| P8["JM1-8 (D18)"]
  V33["JM1-2 3.3V"] --> SENS
  P14 --- FPGA[("PZ7020<br/>xc7z020")]
  P16 --- FPGA
  P18 --- FPGA
  P6 --- FPGA
  P8 --- FPGA
```

### Load a bitstream (RAM only; a power cycle restores the board)

```
cd fpga/<design>      (e.g. vlf_sid_v2, trng)
vivado -mode batch -source program.tcl
```

---

## FPGA designs: what each one uses on JM1

### lockin (digital lock-in amplifier)
```
JM1-6  ADC+ 0..1.0 V        JM1-8  ADC- -> GND at the sensor
JM1-10 drive -> 1kΩ -> node -> 10nF -> GND   (node = analog sine, 0..3.3 V)
JM1-12 sync  (square wave at the drive frequency)
JM1-14 TX / JM1-16 RX  -> USB-serial adapter
Loopback cal: node -> 33kΩ -> JM1-6, 10kΩ from JM1-6 to GND, JM1-8 to JM1-4.
```

### photon_counter (two-detector coincidence)
```
JM1-6  det_a  (3.3 V logic, rising edge = photon)
JM1-8  det_b
JM1-10 gate   (active high; tie to 3.3 V for always-on)
JM1-14 TX / JM1-16 RX
```

### correlator (two-channel cross-correlator)
```
JM1-6  VAUX1+ ch A (0..1.0 V)   JM1-8  VAUX1- -> GND at sensor
JM1-9  VAUX9+ ch B (0..1.0 V)   JM1-11 VAUX9- -> GND at sensor
JM1-18 GPS 1PPS (optional, for multi-station sync)
JM1-14 TX / JM1-16 RX
```

### vlf_sid and vlf_sid_v2 (8-station VLF SID receiver; v2 adds lightning TOA)
```
loop antenna (1 m, ~10 turns) -> preamp ~60 dB, 10-50 kHz, bandlimited <60 kHz
  -> 0.5 V bias -> 100Ω -> JM1-6 (ANTENNA+)   + 2.2nF to JM1-8 (ANTENNA-)
JM1-18 GPS 1PPS      JM1-14 TX / JM1-16 RX
Run the preamp's last stage from JM1-2 (3.3 V) so it cannot exceed 3.3 V.
```

### trng (ring-oscillator TRNG)
```
JM1-14 TX / JM1-16 RX   (no analog pins; XADC reads on-chip temperature)
```

---

## Teensy 4.1 sketches

Pin numbers are Teensy 4.1 digital pins. `A0=14, A1=15, A2=16, A3=17`.
`Serial1 = pin 0 (RX1) / pin 1 (TX1)`, `Serial2 = pin 7 (RX2) / pin 8 (TX2)`.

### resonance_sweep / body_resonance (MPU-6050 vibration)
```
MPU-6050 #0:  SDA -> pin 18,  SCL -> pin 19,  VCC 3.3 V,  GND
body_resonance: up to 6 MPU-6050 on the same I2C bus (AD0 strapping for addresses)
exciter (shaker/buzzer): any PWM/DAC pin to its driver (resonance_sweep)
```

### elf_logger (0.25–45 Hz ELF spectrum)
```
A0 (14) <- amplifier output, 0..3.3 V centred on 1.65 V
pin 0 (RX1) <- GPS TX (NMEA 9600)      pin 2 <- GPS 1PPS      (both optional)
SD card in the Teensy slot
Front end: coil or two electrodes -> instrumentation amp gain ~1000 -> 1.65 V bias -> A0
```

### hemisync_gen (binaural beats)
```
MQS audio (no audio board):
  pin 12 -> 220Ω -> 10µF(+ to pin) -> headphone LEFT
  pin 10 -> 220Ω -> 10µF(+ to pin) -> headphone RIGHT
  GND -> headphone sleeve
pin 2 -> square wave at pair-0 beat frequency (marker)
```

### strobe_driver (flashing-light stimulator — read the header's seizure warning)
```
pin 5 -> channel A LED driver   pin 6 -> channel B LED driver
pin 3 -> flash marker           pin 4 -> trial marker
pin 7 <- external trigger in    A0 (14) <- light sensor for `check`
pin 8 <- ABORT button to GND (internal pull-up; kills the light in the ISR)
LED: pin -> 470Ω -> LED -> GND  (small)  or  pin -> 100Ω -> MOSFET gate (bright)
```

### cc1101_scanner (sub-GHz spectrum)
```
CC1101 via SPI0: pin 10 CS, pin 11 MOSI, pin 12 MISO, pin 13 SCK,
                 pin 2 GDO0 (optional), 3.3 V, GND
second CC1101 (optional): pin 9 CS2, SPI bus shared
```

### schumann_monitor (ADS1256 24-bit, H + E channels)
```
ADS1256: pin 13 SCK, pin 11 MOSI(DIN), pin 12 MISO(DOUT), pin 10 CS,
         pin 9 DRDY, pin 8 RESET, 5 V, GND
  AIN0/AIN1 = H channel (induction coil + preamp)
  AIN2/AIN3 = E channel (ball antenna + electrometer)
pin 0 (RX1) <- GPS NMEA 9600    pin 2 <- GPS 1PPS    SD card in the slot
```

### rf_survey (AD8318 RF power meter)
```
AD8318 module: VCC 5 V, GND, VOUT -> 10kΩ -> A0 (14), 10nF A0->GND
antenna/filter -> AD8318 RF input (SMA)
pin 0 (RX1) <- GPS NMEA 9600 (for `survey`)   pin 3 -> pulse marker   SD card
```

### sleep_cue (closed-loop sleep cueing — battery power only with electrodes on)
```
A0 (14) <- EEG front end (0.3-45 Hz, centred 1.65 V; Fpz active, mastoid ref)
A1 (15) <- EMG front end (optional; `emg off` uses the EEG high band)
MQS audio: pin 12 -> 470Ω -> 10µF -> earbud L,  pin 10 -> ... -> R,  GND sleeve
pin 3 -> cue marker.   SD card holds CUE###.WAV, logs, the sealed key.
```

### kirlian_logger (controlled Kirlian — build the interlocked HV rig from a documented circuit)
```
A0 (14) GSR: electrode->skin->electrode->100kΩ->3.3 V; junction -> A0
A1 (15) FSR pressure: FSR 3.3 V->A1, 10kΩ A1->GND
A2 (16) corona photodiode (transimpedance amp)
A3 (17) HV-present pickup (isolated, 1M/1nF + diode detector)
pin 2 -> HV ENABLE (to the interlock; high only during an armed exposure)
pin 3 -> camera trigger     pin 4 <- foot/hand switch to GND (held to expose)
This board MEASURES and interlocks only; it does NOT generate the high voltage.
```

### nuisance_logger (signal + vibration/B-field/sound/mains veto)
```
A0 (14) SIGNAL    A1 (15) B-FIELD (fluxgate/coil)
A2 (16) SOUND (electret mic + amp)    A3 (17) MAINS pickup (buffered)
MPU-6050 (vibration): SDA pin 18, SCL pin 19, 3.3 V, GND     SD card
```

### vlf_station (GPS-aware bridge for the VLF station) and fpga_uart_bridge
```
FPGA UART : pin 0 (RX1) <- FPGA JM1-14 (TX),  pin 1 (TX1) -> FPGA JM1-16 (RX)
GPS NMEA  : pin 7 (RX2) <- GPS TX (9600)
GPS 1PPS  : GPS PPS -> pin 2  AND -> FPGA JM1-18   (one line, two inputs)
GND common: Teensy GND -- FPGA JM1-4 -- GPS GND
```

---

## ESP32 Schumann generator

`ESP32` (classic, WROOM-32/32E — has the DAC). The ESP32-S3 variant uses LEDC
PWM + an RC filter in place of the DAC (GPIO17).

```
GPIO25 (DAC1) -> waveform 0..3.3 V (centred 1.65 V)   [S3: GPIO17 PWM 78 kHz -> 10kΩ -> 100nF]
coil driver: DAC -> op-amp gain 1..3 (e.g. LM358, input biased 1.65 V)
          -> complementary emitter follower (BD139/BD140) -> coil -> R_SENSE -> GND
GPIO34 (ADC) <- top of R_SENSE through 10kΩ, 100nF to GND   (0..3.3 V)
GPIO35 (ADC) <- optional Hall/fluxgate analog out (for `verify a`)
GPIO27       <- optional fluxgate frequency output (for `verify f`)
GPIO0 (BOOT) <- marks threshold in `phosphene` mode / stop
GPIO2        -> LED (on while the field is on)
Phone page: Wi-Fi AP "SCHUMANN-xxxx", password schumann1
```

---

## STM32 + SX1262 RF resonance probe

Written for the DX-LR20 LoRa kit (STM32 + SX1262). Change the four pin defines
for your board.

| SX1262 | STM32 (default) | Teensy | ESP32/generic |
|---|---|---|---|
| NSS (CS) | PA4 | 10 | configure in sketch |
| DIO1 | PB1 | 3 | |
| NRST | PB0 | 5 | |
| BUSY | PA3 | 4 | |
| MOSI/MISO/SCK | board SPI defaults | | |

Two boards, two antennas facing each other with room for the sample between.
Build for STM32 with `stm32/rf_resonance/build.bat` (passes RadioLib's pin casts
that the STM32 core 3.x needs).

---

## Full VLF SID station

Reference rig: PZ7020 FPGA + Teensy 4.1 (GPS-aware bridge) + ESP32-32E (spare)
+ RTL-SDR + GPS/PPS. Full run sequence and the GPU-rig caveat: `docs/station-setup.md`.
The RTL-SDR cannot receive VLF (24 kHz) directly — it does the 30 MHz riometer
complement; the FPGA does VLF at 390 kS/s.

```mermaid
flowchart TB
  subgraph FE["Front end"]
    LOOP["1 m loop antenna<br/>+ ~60 dB preamp<br/>10-50 kHz"]
    DIP["30 MHz dipole"]
  end
  subgraph FPGA["PZ7020 FPGA (vlf_sid_v2.bit)"]
    ANT["JM1-6/8 antenna"]
    FUART["JM1-14/16 UART"]
    FPPS["JM1-18 1PPS"]
  end
  subgraph TEENSY["Teensy 4.1 (vlf_station.ino)"]
    S1["pin 0/1 Serial1 ↔ FPGA"]
    S2["pin 7 RX2 ← GPS NMEA"]
    TPPS["pin 2 ← 1PPS"]
    USB["USB → PC"]
  end
  GPSMOD["GPS module"]
  SDR["RTL-SDR"]
  PC["PC: vlf_host.py --gps-bridge --push<br/>riometer_host.py --push<br/>sid_server.py + dashboard"]

  LOOP --> ANT
  FUART <--> S1
  GPSMOD -->|NMEA 9600| S2
  GPSMOD -->|1PPS| TPPS
  GPSMOD -->|1PPS| FPPS
  S1 --- USB --> PC
  DIP --> SDR -->|USB| PC
```

Timing: the one GPS 1PPS line fans out to both the Teensy (pin 2) and the FPGA
(JM1-18). NMEA goes to the Teensy on Serial2 so Serial1 stays free for the FPGA.
`vlf_host.py --gps-bridge` then stamps every window with true GPS UTC.

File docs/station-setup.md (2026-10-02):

# VLF SID station on your rig (FPGA + Teensy + ESP32 + SDR + GPS)

Your hardware: PZ7020 FPGA + Teensy 4.1 (wired together, currently running the
GPU matrix-math job), ESP32-32E, an RTL-SDR, and a GPS with PPS — the same GPS
and the same NMEA/PPS convention as your past .ino builds (NMEA 9600 on a
hardware serial, PPS on an interrupt pin).

This is the space-weather station built from item #180. Each part has one job.

## Who does what

| Part | Job | Software |
|---|---|---|
| **FPGA (PZ7020)** | the VLF receiver: 8 Navy stations at once, 390 kS/s, lightning time-of-arrival (v2) | `fpga/vlf_sid_v2/build/vlf_sid_v2.bit` |
| **Teensy 4.1** | GPS-aware bridge: passes the FPGA's UART to the PC AND reads the GPS so windows get true GPS time | `teensy/vlf_station/vlf_station.ino` |
| **GPS + PPS** | the clock: NMEA to the Teensy, 1PPS to BOTH the Teensy and the FPGA | — |
| **RTL-SDR** | the complement the SDR can actually receive: 30 MHz riometer (flare absorption) + 245 MHz solar bursts | `tools/riometer_host.py` |
| **ESP32-32E** | not required for the station — the PC does the uploading. Spare: run the Schumann generator on it, or use it later as a standalone WiFi upload node | `esp32/schumann_gen` (no station-uploader firmware is written for it; `vlf_host.py --push` uploads from the PC) |
| **PC** | runs `vlf_host.py` and `riometer_host.py`, and `sid_server.py` for the dashboard | — |

The RTL-SDR tunes 24 MHz and up, so it cannot receive VLF (24 kHz) directly —
that is exactly why the FPGA does the VLF at 390 kS/s and the SDR does the HF
riometer. The two together cover the flare from two independent angles.

## Your GPU rig stays put

Loading `vlf_sid_v2.bit` over JTAG (`program.tcl`) writes the FPGA's RAM
configuration only. It temporarily replaces whatever is running (your GPU
matrix-math bitstream); a power cycle brings the board back exactly as it was.
So: switch to VLF when you want to run the station, power-cycle to return to the
GPU job. Nothing is written to flash, nothing about the GPU wiring changes.

## Wiring for VLF mode

The FPGA↔Teensy link you already have for the GPU job carries the UART in VLF
mode too. Add the antenna, the GPS, and (if using the Teensy bridge) confirm the
UART pins:

```
Antenna/preamp (1 m loop + ~60 dB preamp, 10-50 kHz) -> FPGA JM1-6 (ANTENNA+, 0..1.0 V)
                                                        FPGA JM1-8 (ANTENNA-, preamp ground)
FPGA UART: JM1-14 (TX) -> Teensy pin 0 (RX1)
           JM1-16 (RX) <- Teensy pin 1 (TX1)
GPS NMEA (9600):        GPS TX -> Teensy pin 7 (RX2)
GPS 1PPS:               GPS PPS -> Teensy pin 2  AND  -> FPGA JM1-18 (C20)     (one line, two inputs)
GND common:             Teensy GND -- FPGA JM1-4 -- GPS GND
RTL-SDR:                USB to the PC, antenna = a 30 MHz dipole (2.4 m legs) or a 2-element Yagi
```

The GPS wiring is the same idea as elf_logger / schumann_monitor (NMEA on a
hardware serial, PPS on an interrupt pin); here NMEA is on Serial2 (pin 7) so
Serial1 (pins 0/1) is free for the FPGA. The one 1PPS line fans out to both the
Teensy (for the timestamp) and the FPGA JM1-18 (for GPS-second windows).

## Run it

1. **Load the receiver** (Vivado Tcl shell):
   ```
   cd P:/Downloads/freq-lab/fpga/vlf_sid_v2
   source program.tcl
   ```
   LED R19 blinks at 1 Hz when it is running.
2. **Flash the Teensy** with `teensy/vlf_station/vlf_station.ino`.
3. **Set the preamp gain** (the Teensy is now the serial port):
   ```
   python tools/vlf_host.py COM_TEENSY level
   ```
   aim for 30-300 counts RMS, zero clipping.
4. **Confirm the stations and the GPS:**
   ```
   python tools/vlf_host.py COM_TEENSY scan       # names the Navy stations you hear
   python tools/vlf_host.py COM_TEENSY info       # PPS alive, windows advancing
   ```
   `info` reads the FPGA; the Teensy also answers `@gps` with the GPS time.
5. **Log, GPS-stamped, uploading to the dashboard:**
   ```
   python tools/sid_server.py --goes             # on any always-on machine
   python tools/vlf_host.py COM_TEENSY log --goes --gps-bridge --station HOME --push http://SERVER:8750
   ```
   `--gps-bridge` stamps every window with the GPS UTC from the Teensy instead
   of the PC clock. Add `sferics --gps-bridge --push ...` on a second run for the
   lightning time-of-arrival network.
6. **The SDR complement** (another terminal):
   ```
   python tools/riometer_host.py run --freq 30.0 --station HOME --push http://SERVER:8750
   ```
   30 MHz cosmic-noise absorption dips line up with the same flares the VLF
   stations step on, from an independent receiver.

Open `http://SERVER:8750/` for the live dashboard: station levels, GOES overlay,
flare alerts, riometer absorption, and (with sferics on two sites) the
time-of-arrival strokes.

## What's verified vs. what needs the hardware run

- `vlf_sid_v2` bitstream: Vivado-built, timing met, 0 critical warnings;
  simulation 59 + 19 checks bit-exact. `program.tcl` fixed to load it.
- `vlf_station.ino`: compiles (50 KB); its NMEA parser is PC-tested 11/11.
- `vlf_host.py --gps-bridge`: tested 21/21 against a software board + bridge.
- `riometer_host.py`: tested 8/8.
- Not yet run on real hardware. The first run is the acceptance test in
  the run sequence above, now with the Teensy GPS bridge in the loop.

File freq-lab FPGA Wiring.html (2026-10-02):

Puzhi PZ7020-StarLite · Zynq XC7Z020 · header JM1

# freq-lab FPGA wiring

Your board has three designs ready to load. Each one turns the FPGA into a different lab instrument that you run from the PC over a 3-wire serial link. This sheet covers what each one does, what plugs into which pin, and what a working first run looks like.

## The three designs

Lock-in amplifierStart here

A signal generator and a very sensitive meter in one.

Sends a sine wave into something, then measures how strongly and how late it answers at exactly that frequency, even when the answer is buried in noise. Sweep the frequency to draw a resonance curve, or let it lock onto a resonance and follow it.

First test

3 resistors and 1 capacitor

Later

coils, piezos, crystals, LC circuits, sensors

Show its pins

Photon counter

A two-channel pulse counter that spots coincidences.

Counts pulses from two light detectors, and counts how often both fire within a time window you set, in 20 ns steps. Subtracting the chance overlaps tells you whether both detectors are seeing the same light.

First test

any two 3.3 V pulse sources

Real use

two detector modules with 3.3 V pulse outputs

Show its pins

Two-channel correlator

Compares two analog signals in real time.

Samples two inputs about 195,000 times a second each and reports how alike they are (coherence, −1 to +1) and at what time offset. Built for two-station ELF antenna experiments; a GPS input lines up two boards.

First test

one signal into both inputs

Real use

two sensors with amplifiers, GPS optional

Show its pins

### Do the lock-in loop-back first

It needs no sensors. Three resistors and a capacitor feed the board's own output back into its input, so one run proves the whole chain: loading the design, the serial link, the signal output, the ADC and the math. After that, anything that misbehaves is the sensor, not the setup. Then dry-run the photon counter with test pulses, then the correlator.

All three: build clean in Vivado 2026.1, timing met, simulation passes. None has run on the real board yet.

## JM1 pin map

Lock-in Photon counter Correlator

Lock-in uses JM1 5, 6, 7, 8, 10, 12, 14, 16, plus GND.

- Analog in (ADC)
- Signal out
- Digital in
- Serial to PC
- Fan
- 3.3 V out
- 5 V out
- Ground
- Free

Odd pins are one row and even pins the other; pin 2 sits right next to pin 1. Pin 1 is marked on the board (square pad, triangle or a "1" on the silkscreen). The small codes next to each pin (E17, H16…) are the FPGA ball names from Puzhi's pin sheet.

Every signal pin on JM1 is 3.3 V logic. Bank 35 can be switched to 1.8 or 2.5 V, but these designs assume the default 3.3 V. JM2 is not used.

## Before you connect anything

- 3.3 V maximum on any signal pin. JM1-1 is 5 V. Never let it touch a signal pin.
- ADC pins read 0 to 1.0 V (JM1-6, 8, 9, 11). Above 1 V just reads full scale. Above 3.3 V can damage the chip.
- Detector inputs take 3.3 V logic pulses only. Never wire a SiPM, APD or photomultiplier straight in. Their bias runs from tens of volts to over a thousand. A module with a built-in discriminator or comparator output is what goes here.
- Serial is 3.3 V. Use the Teensy 4.1 bridge or a 3.3 V USB-serial adapter, never a 5 V one.
- Check the fan's PWM wire first. Power the fan, leave its PWM wire unplugged, and measure it to ground. 3.3 V or less is fine. About 5 V needs a small transistor in between; don't connect it directly.
- One shared ground. Teensy, sensors, detectors and GPS all connect to board GND (JM1-3, 4 or 33–36).
- Rewire with the board unplugged.

## Lock-in amplifier

Vivado: builds, timing met with 11.9 ns to spare, 3.6 % of the chip, 0.13 W · Simulation: amplitude within 0.1 %, phase within 0.4° · Hardware: not run yet

The FPGA generates a sine wave digitally and sends it out of JM1-10 as a very fast on/off stream. The 1 kΩ + 10 nF filter smooths that into a real sine, from micro-hertz steps up to about 100 kHz. Whatever comes back is sampled on JM1-6, 390,625 times a second.

The FPGA multiplies those samples by its own sine and cosine and averages them. Anything that isn't at the drive frequency, like noise and mains hum, averages toward zero. What's left is the amplitude and the phase lag of the response at exactly the drive frequency.

### First test: loop-back

The board's output goes through the filter. The divider brings it under 1 V, and it comes straight back into the ADC. Add the PC link from the shared section below. Parts: 1 kΩ, 33 kΩ and 10 kΩ resistors, a 10 nF capacitor, a breadboard and jumpers.

### Commands

From P:\Downloads\freq-lab, after pip install pyserial once. COM7 stands for your Teensy's port (Device Manager → Ports).

python tools/lockin_host.py COM7 id
python tools/lockin_host.py COM7 cal
python tools/lockin_host.py COM7 sweep 50 2000 40 --log --amp 0.2 --out loop.csv
python tools/lockin_host.py COM7 off

### What working looks like

id prints the design's ID. cal measures the loop's delay and saves it. The sweep should then read almost the same amplitude at every frequency with a lag near 0°, because nothing in the loop resonates. If you get that, the whole chain works.

### LEDs and sync

LED1 blinks about once a second while the design runs. LED2 toggles after every finished measurement. JM1-12 puts out a square wave at the drive frequency for a scope trigger.

### Measuring something real

Drive the thing you're testing from the filter node, such as a coil, piezo or LC circuit. Bring its response back into JM1-6 through the analog front end in the correlator section. That holds the pin at 0.5 V and keeps the swing in range. Sweep across the range you care about, then track 440 --step 0.05 follows a resonance near 440 Hz as it drifts.

## Photon coincidence counter

Vivado: builds, timing met with 11.6 ns to spare, 1.1 % of the chip, 0.11 W · Simulation: 12 of 12 checks · Hardware: not run yet
Fixed tonight: pulses that land in the same 20 ns tick now count as a coincidence (they used to be missed), and each pulse counts toward at most one pair.

Each detector sends one short 3.3 V pulse per photon. The FPGA checks both inputs every 20 ns and counts every pulse on each channel; these are the singles. When A and B fire within the window you set, in either order, it also counts a coincidence. The window is set in 20 ns ticks, so window 10 means within ±200 ns.

Two detectors watching unrelated light still line up by chance now and then. The accidental command works out how many of those to expect from the singles. The coincidences left over are photons hitting both detectors together.

Power the detector modules from their own supply and share ground with the board. For a dry run without detectors, any two 3.3 V pulse sources work: a function generator, or a spare Teensy toggling two pins. The gate input has an internal pull-up, so leaving it unconnected means counting is on.

### Commands

This one is interactive: start it with just the port, then type at the photon> prompt.

python tools/photon_host.py COM7
photon> window 10      # within ±200 ns
photon> run 10         # count 10 s, print results
photon> accidental     # chance overlaps vs real
photon> csv run1.csv 60 5
photon> quit

### What working looks like

It prints the design's ID as soon as it connects. run 10 prints singles A, singles B, coincidences and elapsed time. In a dry run, pulses sent to both inputs at the same moment give coincidences equal to the singles, while two unrelated pulse trains give about the accidental number.

LED1 blinks about once a second. LED2 is on while counting.

## Two-channel correlator

Vivado: builds, timing met with 8.1 ns to spare, 2.4 % of the chip, 0.12 W · Simulation: 7 of 7 · Hardware: not run yet
Fixed tonight: the ADC now samples your two inputs (it was set to read the chip's own supply voltage), channel B moved to JM1-9/11 (the old pins weren't ADC pins), and the ADC's input wiring inside the chip was corrected.

The on-chip ADC samples channel A and channel B in turn, about 195,000 times a second each. Over each window it adds up A², B², A×B and the averages, and the PC turns that into a coherence between −1 and +1.

Two sensors picking up the same distant source read high, for example two ELF antennas hearing the Earth–ionosphere (Schumann) resonances. Noise that's local to each sensor doesn't line up and reads near 0. A GPS module's once-a-second pulse lets two boards at different places line up their sample counts.

Channel B is on the odd row: JM1-9 and JM1-11. Older notes said 10 and 12, but those aren't ADC pins. With nothing on JM1-18 it reads low, so the GPS input is safe to leave empty.

### Analog front end (one per ADC input)

56 kΩ to 3.3 V and 10 kΩ to ground hold the ADC pin at 0.5 V, the middle of its 0 to 1 V range. Capacitor C passes the sensor's signal and blocks its DC, and it sets the lowest frequency that gets through. 100 nF passes above about 190 Hz, which is fine for the lock-in. For ELF signals use 220 µF non-polarized, which passes down to about 0.1 Hz; give it about 10 s after power-up to settle. For channel B, use JM1-9 (+) and JM1-11 (−).

### Commands

Interactive, like the photon counter: start with the port, then type at corr>.

python tools/correlator_host.py COM7
corr> adc             # both ≈ 2048 on the bias
corr> window 100000   # ≈ 0.5 s per window
corr> stream 5        # coherence of 5 windows
corr> lagplot 16      # offsets ±16 × 5.12 µs
corr> quit

### What working looks like

adc shows both channels near 2048 (0.5 V) with just the front ends connected. With the same signal into both channels, stream 5 prints coherence close to +1.000. Two unrelated signals give close to 0.

For ELF work use long windows, because the first Schumann mode is 7.8 Hz: window 1000000 is about 5 s. stream waits at most 10 s per window, so stay under about 1,900,000.

LED1 blinks about once a second. LED2 is on while a window is being captured.

Known limit: lagplot only uses the last 256 samples and wraps around at the ends, so values away from lag 0 are a little off. Coherence at lag 0 is exact.

## PC link, fan and loading a design

### Serial link to the PC

Load teensy/fpga_uart_bridge onto the Teensy and the PC sees the FPGA as the Teensy's COM port (115200 baud). The wires cross: FPGA TX goes to Teensy RX, and Teensy TX goes to FPGA RX. A 3.3 V USB-serial adapter works the same way: its RX to JM1-14, its TX to JM1-16, and GND to GND.

### Fan

All three designs run the fan the same way: 25 kHz PWM on JM1-5, with the tach read on JM1-7 (the FPGA has a pull-up on it). Hold KEY1 on the board for full speed. A 12 V fan needs its own 12 V supply with its ground tied to the board's. Measure the PWM wire first (see the safety list).

### Loading a design onto the board

1. Wire everything with the board unplugged, then power it.
2. Set the boot-mode jumpers to JTAG.
3. Plug the board's JTAG USB-C into the PC. It's the port wired to the onboard FT232H and shows up as an FTDI device. The other USB-C is a CH340 serial port to the ARM side, which these designs don't use.
4. Open Vivado 2026.1 Tcl Shell from the Start menu and type the two lines below, using the folder of the design you want.
5. LED1 starts blinking about once a second, so it's running. A design loaded over JTAG lasts until power-off, so load it again after a power cycle.

cd P:/Downloads/freq-lab/fpga/lockin      # or fpga/photon_counter, fpga/correlator
source program.tcl

To rebuild after changing any HDL, double-click build_all_vivado.bat in P:\Downloads\freq-lab\fpga. It rebuilds all three, about 8 minutes.

## The other freq-lab sketches

These run on the Teensy or STM32, not the FPGA. All of them compile; none has run on hardware yet.

Sketch | Runs on | What it does
teensy/resonance_sweep | Teensy 4.1 + MPU-6050 + a shaker | Shakes an object from 0.05 to 400 Hz and reads the response off the accelerometer: resonance curve, Q, tracking, ring-down.
teensy/body_resonance | Teensy 4.1 + up to six MPU-6050 | Vibration spectra at several points on a body or structure, the transfer between two points, and heartbeat recoil (ballistocardiogram).
teensy/hemisync_gen | Teensy 4.1 + headphones | Binaural tone pairs with exact beat frequencies, pink and surf noise, and blind or sham sessions for testing.
teensy/elf_logger | Teensy 4.1 + amplifier + coil or electrodes, GPS optional | Logs the 0.25–45 Hz spectrum with mains rejection: Schumann modes, SRI's 19 bands, GPS-stamped raw waveform.
teensy/strobe_driver | Teensy 4.1 + LEDs | Flashing light at 0.1–100 Hz in randomized trial blocks, with a light-sensor check. Flashing light can trigger seizures in photosensitive people, so read the warning at the top of the file first.
teensy/cc1101_scanner | Teensy 4.1 + CC1101 | Sub-GHz spectrum scanner, 300–928 MHz, peak hold, CSV export.
teensy/fpga_uart_bridge | Teensy 4.1 | Passes the FPGA's serial link through to USB. All three FPGA designs use it.
stm32/rf_resonance | 2 × STM32 + SX1262 (DX-LR20 kit) | One radio transmits and the other measures across 900–928 MHz, with a sample between the antennas, to look for absorption dips.

Pin data from Puzhi's PZ-StarLite connector sheet and schematic. Designs built and timing-checked in Vivado 2026.1 on Sep 30, 2026.

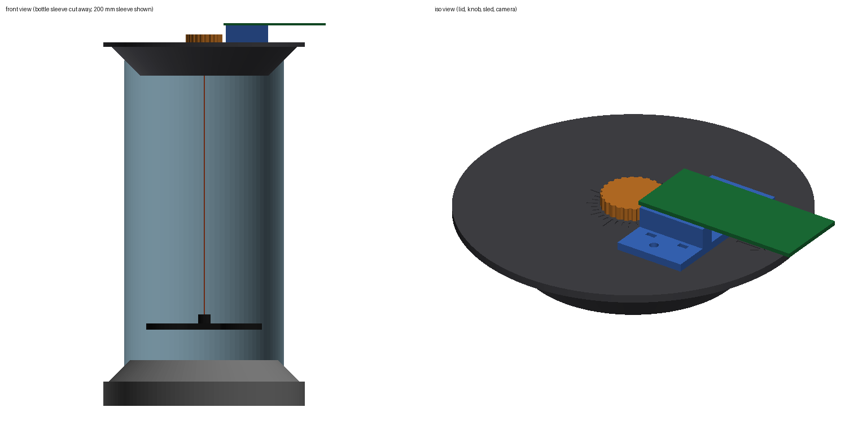
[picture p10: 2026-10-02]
torsion_pendulum/cad/assembly.png

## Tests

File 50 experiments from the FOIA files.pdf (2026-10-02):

# 50 experiments from the FOIA files

Oct 1, 2026 · @'P

## How to use this list

### Every idea traces to a declassified US government document, and every one is buildable from your kit plus at most a cheap sensor. Pick by number and I'll build the ones you

choose.

### Sources: the CIA's FOIA reading room (CREST, including the STAR GATE / SRI / SAIC files), plus DIA, Army and Navy reports released under FOIA. Each item links its

document.

### Hardware assumed: the PZ7020 FPGA (lock-in, coincidence counter, correlator), 2×

Teensy 4.1, about 15 ESP32s, 3 GPS modules, CC1101s, the SX1262 kit, 6× MPU-6050, INA219s, the logic analyzer and the A1 mini. Extra parts come with rough prices.

### Safety filter: nothing that transmits above legal ISM power, exposes anyone to strong

RF, high voltage or loud infrasound, or is aimed at other people. Self-tests with light, sound or biofeedback carry their warnings.

### Evidence grade: A = solid physics or a replicated result. B = reported in the documents but never properly re-tested. C = an extraordinary claim most scientists reject; worth

running only blinded, with the analysis fixed in advance.

### Each item gives the claim, the document, the build, and the result that would actually

matter.

## Shortlist

### One item cleared the "we have to rerun that" bar: #19, solar flares on Navy VLF. An Air Force study of 4,500+ flares found VLF signals peak 2.7 minutes after the X-ray peak, and

your board can measure that lag on 8 stations at once. It is now built as fpga/vlf_sid . No

### psi item clears the bar on evidence; #32 and #34 are here because they are cheap and

decisive.

50 experiments from the FOIA files

# | Experiment | Why it made the list | Where it stands

19 | Solar flares on Navy VLF | Grade A physics with a published number to check: 2.7 min lag (2.1–3.4 by transmitter) | Built. Vivado 2026.1: exit 0, timing met (+6.3 ns), 17 % LUTs, 0.15 W. Simulation: 33/33 checks, every I/Q value bit-exact vs a reference model. Needs a loop antenna, a preamp and a 3.3 V USB-serial adapter; GPS optional
24 | Do rocket launches ring the ionosphere? | Never replicated; the Navy saw it "very poorly in San Diego", and Vandenberg launches are ~350 km from you | Next up. Runs on the ELF logger you have, plus a large coil
14 | EEG-gated sleep learning | The one body item with modern support: meta-analysis g = 0.29 | Needs the EEG headband build
32 | The decisive test SAIC never ran | Proposed in 1995 to settle "push vs pick"; no record it was ever run | Needs the FPGA TRNG (#36) first
34 | Swann's steel-box run | About 40 runs settle the claim, the cheapest decisive test here | A ~$5 noise TRNG and a steel ammo can
2 | Torsion pendulum in a bell jar | SRI reported 5:1 changes from 1 m with no statistics; a lock-in phase readout makes it a clean blind test | Built Oct 1, v2 (not yet run on hardware): the bottle is cut to a sleeve that wedges on printed 45-degree cones (fits any 100-120 mm 2-liter), flat printed floor with a backlit window, ESP32-S3 camera tracker, logged sessions with exact stats, in freq-lab/torsion_pendulum

### Next for #19: wire a loop antenna and preamp to JM1-6/8, load vlf_sid.bit , then run

vlf_host.py scan to see which stations you hear.

## SRI/ SAIC lab experiments

The lab side of the remote-viewing program: real instruments, mostly one-subject pilots, almost none re-tested blind. Each build adds the control the original lacked.

# | Experiment | Why it made the list | Where it stands

6 | Being watched remotely | SAIC got p < 0.005 over 48 sessions; the later meta-analysis shrank it to d = 0.11 | Paused until there's a GSR sensor and a second person to watch. Plan: GSR amp on a Teensy plus the ESP32-S3 camera
36 | Health-tested FPGA TRNG | An auditable random target picker for every test here, the way SRI certified its generator; #32 needs it first | Queued (your pick). Runs on the Zynq board you have
38 | Sonic boom and infrasound array | NASA logged about 800 booms from 0.1 Hz (1964); the same array would also hear the launches in #24 | Queued (your pick). 3–4 ESP32 nodes with SDP31 pressure sensors and GPS
# | Experiment | What the file says | Your build | Grade | Pick

1 | Gradiometer on/off test (https://documents3.theblackvault.com/documents/stargate/pdfs/CIA-RDP96-00787R000700100006-0.pdf) | Swann sat 4 m from a superconducting gradiometer during random activity/rest periods: 42 events in activity periods vs 21 in rest, p = 0.004 (SRI, 1974). | Two FG-3+ fluxgates (~$110) as a gradiometer; the FPGA times their pulse periods at 50 MHz; a third sensor on GPS time cancels common signals; an RNG sets the schedule and the analyst stays blind. | C | ▾

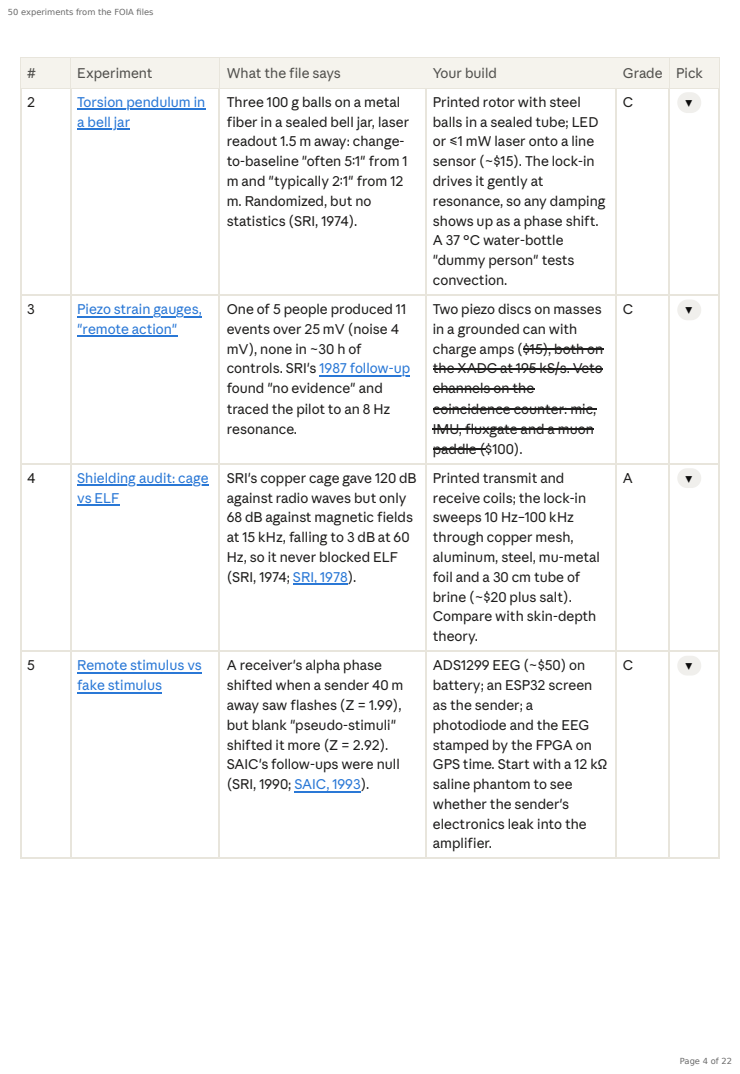
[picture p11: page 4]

# | Experiment | What the file says | Your build | Grade | Pick
2 | Torsion pendulum in a bell jar (https://documents3.theblackvault.com/documents/stargate/pdfs/CIA-RDP96-00787R000700100006-0.pdf) | Three 100 g balls on a metal fiber in a sealed bell jar, laser readout 1.5 m away: change-to-baseline "often 5:1" from 1 m and "typically 2:1" from 12 m. Randomized, but no statistics (SRI, 1974). | Printed rotor with steel balls in a sealed tube; LED or ≤1 mW laser onto a line sensor (~$15). The lock-in drives it gently at resonance, so any damping shows up as a phase shift. A 37 °C water-bottle "dummy person" tests convection. | C | ▾

3 | Piezo strain gauges, "remote action" (https://documents3.theblackvault.com/documents/stargate/pdfs/CIA-RDP96-00789R002200100001-6.pdf) | One of 5 people produced 11 events over 25 mV (noise 4 mV), none in ~30 h of controls. SRI's 1987 follow-up (https://documents3.theblackvault.com/documents/stargate/pdfs/CIA-RDP96-00787R000300300001-7.pdf) found "no evidence" and traced the pilot to an 8 Hz resonance. | Two piezo discs on masses in a grounded can with charge amps ($15), both on the XADC at 195 kS/s. Veto channels on the coincidence counter: mic, IMU, fluxgate and a muon paddle ($100). | C | ▾

4 | Shielding audit: cage vs ELF (https://documents3.theblackvault.com/documents/stargate/pdfs/CIA-RDP96-00787R000700100004-2.pdf) | SRI's copper cage gave 120 dB against radio waves but only 68 dB against magnetic fields at 15 kHz, falling to 3 dB at 60 Hz, so it never blocked ELF (SRI, 1974; SRI, 1978). (https://documents3.theblackvault.com/documents/stargate/pdfs/CIA-RDP96-00788R001300040001-4.pdf) | Printed transmit and receive coils; the lock-in sweeps 10 Hz–100 kHz through copper mesh, aluminum, steel, mu-metal foil and a 30 cm tube of brine (~$20 plus salt). Compare with skin-depth theory. | A | ▾

5 | Remote stimulus vs fake stimulus (https://documents3.theblackvault.com/documents/stargate/pdfs/CIA-RDP96-00789R002200630001-8.pdf) | A receiver's alpha phase shifted when a sender 40 m away saw flashes (Z = 1.99), but blank "pseudo-stimuli" shifted it more (Z = 2.92). SAIC's follow-ups were null (SRI, 1990; SAIC, 1993). (https://documents3.theblackvault.com/documents/stargate/pdfs/CIA-RDP96-00789R003100290001-6.pdf) | ADS1299 EEG (~$50) on battery; an ESP32 screen as the sender; a photodiode and the EEG stamped by the FPGA on GPS time. Start with a 12 kΩ saline phantom to see whether the sender's electronics leak into the amplifier. | C | ▾

## The body

The Monroe and Gateway papers make the most specific physiological claims in the files,

### and most of them can be checked with a $50–250 EEG board. Run every body sensor on battery or through a USB isolator, keep audio under 60 dB, and use a sham track every

time.

6 | Being watched remotely (https://documents3.theblackvault.com/documents/stargate/pdfs/CIA-RDP96-00789R003200240001-0.pdf) | Skin conductance changed when a remote observer watched on CCTV during 16 random 30 s periods out of 32: combined p < 0.005 over 48 sessions, effect size 0.36– 0.44 (SAIC, 1994). Later meta-analysis: about d = 0.11. | GSR amp (~$10) on a Teensy; the ESP32-S3 camera streams you to a friend whose screen blanks in control periods; the FPGA RNG sets the schedule, with its hash posted first. You are the only subject. | C | ▾
7 | Target entropy or camera artifact? (https://documents3.theblackvault.com/documents/stargate/pdfs/CIA-RDP96-00789R003000490006-0.pdf) | Session quality tracked the target photo's entropy gradient (ρ = 0.45, n = 28), but re-scanning the same photos dropped it to 0.30, not significant (SAIC, 1994). | Shoot 50 scenes on the ESP32-S3 camera and a phone at different settings, compute SAIC's measure on the Orange Pi, and check its stability across cameras before using it for anything. | B | ▾
8 | ESP teaching machine (https://documents3.theblackvault.com/documents/stargate/pdfs/CIA-RDP96-00787R000200150001-5.pdf) | A 4-choice machine with feedback: one subject hit 29.4% over 2,500 trials (chance 25%), p = 3×10⁻⁷. SRI's own 1989 meta-analysis put forced-choice at d = 0.05 (SRI for NASA, 1975). | ESP32 box with 4 lit buttons; the FPGA TRNG picks each target and commits it by hash before the press; 10⁹ bits checked with the NIST tests. | C | ▾
9 | Geophysical station (https://documents3.theblackvault.com/documents/stargate/pdfs/CIA-RDP96-00788R001800300001-0.pdf) | SRI logged ionospheric disturbances, geomagnetic indices and ELF at 19 frequencies against session scores; "nine of ten" data sets had a disturbance on session day. SAIC later found ρ = −0.05 over ~1,000 trials (SRI, 1984; SAIC, 1993). (https://archive.org/details/cia-readingroom-document-cia-rdp96-00787r000300230001-5) | The VLF receiver from #19, a buried fluxgate for a local K-index, and GPS sidereal time. First measure how often disturbances happen on random days: near solar max it's most days, which makes "nine of ten" meaningless. | C | ▾

# | Experiment | What the file says | Your build | Grade | Pick

10 | Beat-locked EEG (https://apps.dtic.mil/sti/pdfs/ADA141977.pdf) | Monroe told an Army Science Board panel that a 3–5 Hz binaural beat "synchronously drives" both hemispheres; the panel never checked because the lab was "being remodeled" (Army Science Board, 1983; Monroe paper). (https://documents3.theblackvault.com/documents/stargate/pdfs/CIA-RDP96-00788R001700210004-8.pdf) | The Teensy plays a 4 Hz beat binaurally, monaurally and not at all, in random order; two EXG front ends (~$12 each) at C3/C4 feed the XADC; the FPGA lock-in uses the beat as its reference. A saline-sponge phantom rules out pickup from the headphones. | B | ▾
11 | Gateway session polygraph (https://documents2.theblackvault.com/documents/cia/CIA-RDP96-00788R001700210016-5.pdf) | The 1983 Army assessment says Hemi-Sync makes both hemispheres "equal in amplitude and frequency", holds you at "the threshold of sleep" and lowers blood pressure; one meditator held it "for over 15 minutes" (US Army, 1983). | ADS1299 at F3/F4, C3/C4 and O1/O2 plus eye and muscle channels, a MAX30102 pulse sensor ($5) and a BP cuff ($30). Beats hidden in surf noise vs the same track without them, coded at random; faint probe tones you answer with a tap. Add the report's humming exercise and its 6.8–7.5 Hz body-micromotion claim on your ballistocardiograph rig. | B | ▾
12 | Holding sleep stages (https://documents3.theblackvault.com/documents/stargate/pdfs/CIA-RDP96-00788R001700210052-5.pdf) | Monroe claimed beats can "hold the subject into any of the various stages of sleep", and a beta signal after REM wakes you without grogginess (Monroe Institute bulletin, undated). | Frontal EEG/EOG headband, IMU and sleep earbuds. Nights randomly get a 2 Hz beat from stage N2 or a no-beat track; wake-ups get a beta ramp, a plain ramp or an alarm. Stage the night with YASA; reaction-time test on the AMOLED watch. | B | ▾
13 | REM-cued lucid dreams (https://archive.org/details/cia-readingroom-document-cia-rdp96-00789r003100140001-2) | A mask giving "one or two flashes per second" during REM "enhanced the frequency of lucid dreaming"; the appended LaBerge study logged 35 lucid dreams, 32 in REM, verified by eye signals (SAIC draft protocol, 1991). | Printed mask with 2-channel EOG, an IMU and dim red LEDs on an ESP32-S3. Nights randomly get REM flashes, REM audio, or flashes in non-REM sleep as an active sham; score the agreed left-right eye signals. | B | ▾

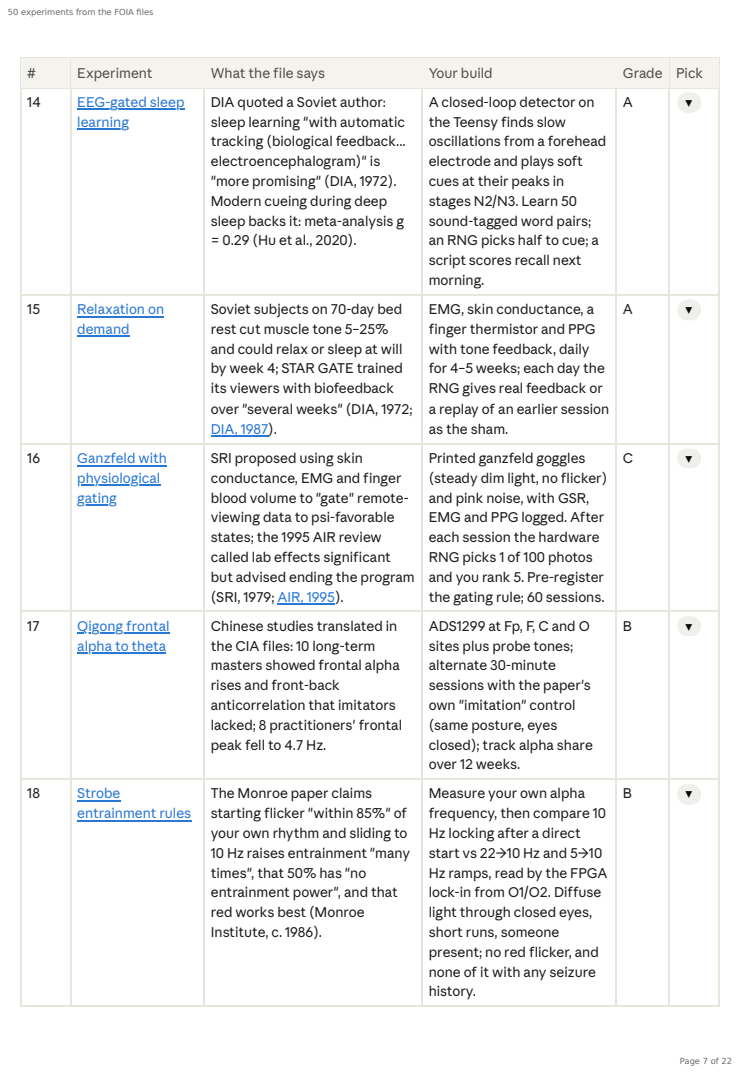
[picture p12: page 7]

14 | EEG-gated sleep learning (https://archive.org/details/cia-readingroom-document-cia-rdp96-00788r001300010001-7) | DIA quoted a Soviet author: sleep learning "with automatic tracking (biological feedback... electroencephalogram)" is "more promising" (DIA, 1972). Modern cueing during deep sleep backs it: meta-analysis g = 0.29 (Hu et al., 2020). | A closed-loop detector on the Teensy finds slow oscillations from a forehead electrode and plays soft cues at their peaks in stages N2/N3. Learn 50 sound-tagged word pairs; an RNG picks half to cue; a script scores recall next morning. | A | ▾

15 | Relaxation on demand (https://archive.org/details/cia-readingroom-document-cia-rdp96-00788r001300010001-7) | Soviet subjects on 70-day bed rest cut muscle tone 5–25% and could relax or sleep at will by week 4; STAR GATE trained its viewers with biofeedback over "several weeks" (DIA, 1972; DIA, 1987). (https://archive.org/details/cia-readingroom-document-cia-rdp96-00788r001000010001-0) | EMG, skin conductance, a finger thermistor and PPG with tone feedback, daily for 4–5 weeks; each day the RNG gives real feedback or a replay of an earlier session as the sham. | A | ▾

16 | Ganzfeld with physiological gating (https://archive.org/details/cia-readingroom-document-cia-rdp96-00788r001300100001-7) | SRI proposed using skin conductance, EMG and finger blood volume to "gate" remote-viewing data to psi-favorable states; the 1995 AIR review called lab effects significant but advised ending the program (SRI, 1979; AIR, 1995). (https://archive.org/details/cia-readingroom-document-cia-rdp96-00791r000200180006-4) | Printed ganzfeld goggles (steady dim light, no flicker) and pink noise, with GSR, EMG and PPG logged. After each session the hardware RNG picks 1 of 100 photos and you rank 5. Pre-register the gating rule; 60 sessions. | C | ▾

17 | Qigong frontal alpha to theta (https://archive.org/details/cia-readingroom-document-cia-rdp96-00792r000300440002-5) | Chinese studies translated in the CIA files: 10 long-term masters showed frontal alpha rises and front-back anticorrelation that imitators lacked; 8 practitioners' frontal peak fell to 4.7 Hz. | ADS1299 at Fp, F, C and O sites plus probe tones; alternate 30-minute sessions with the paper's own "imitation" control (same posture, eyes closed); track alpha share over 12 weeks. | B | ▾

18 | Strobe entrainment rules (https://documents3.theblackvault.com/documents/stargate/pdfs/CIA-RDP96-00788R001700210004-8.pdf) | The Monroe paper claims starting flicker "within 85%" of your own rhythm and sliding to 10 Hz raises entrainment "many times", that 50% has "no entrainment power", and that red works best (Monroe Institute, c. 1986). | Measure your own alpha frequency, then compare 10 Hz locking after a direct start vs 22→10 Hz and 5→10 Hz ramps, read by the FPGA lock-in from O1/O2. Diffuse light through closed eyes, short runs, someone present; no red flicker, and none of it with any seizure history. | B | ▾

## TheEarth

### The strongest group: real physics with results you are guaranteed to see, plus one untested Navy claim that your location is well placed to check. Disconnect outdoor

antennas in storms, and call 811 before driving ground rods.

# | Experiment | What the file says | Your build | Grade | Pick

19 | Solar flares on Navy VLF (https://apps.dtic.mil/sti/pdfs/ADA614949.pdf) | Across 4,500+ flares, VLF signal strength peaked an average 2.7 min after the X-ray peak (2.1–3.4 min depending on transmitter) (Air Force Institute of Technology, 2015; a Soviet IGY paper (https://archive.org/details/cia-readingroom-document-cia-rdp80t00246a005400350007-7) on the same disturbances). | The FPGA as a multi-station VLF receiver: a loop antenna and preamp into the XADC, tracking NLK 24.8, NAA 24.0, NML 25.2 and NPM 21.4 kHz on GPS-aligned seconds, compared with the GOES X-ray feed. | A | ▾
20 | Lightning by time of arrival (https://archive.org/details/DTIC_ADA286621) | AFCRL's four-station network timed lightning pulses to microseconds; for 150 European strokes the average error was 31 nautical miles (1 µs ≈ 6 nmi) (AFCRL, 1962). | 3–4 stations (FPGA plus Teensys), each with a whip or loop and GPS PPS, 20–100 km apart; the coincidence counter stamps at 20 ns. Needs friends to host stations. | A | ▾
21 | The 3 kHz notch and tweeks (https://archive.org/details/cia-readingroom-document-cia-rdp78-03424a000400090001-9) | Earth-electrode measurements showed "a pronounced minimum of noise in the neighborhood of 3 kc", using two iron pipes 100 m apart (CIA, 1960). At night the cutoff of "tweek" sferics near 1.7– 1.9 kHz gives the ionosphere's height. | Two ground electrodes 30–100 m apart, a transformer-coupled preamp (~$20) and a loop as a second sensor; Teensy audio at 96 kS/s; nightly spectra and tweek fits (height = c / 2 × cutoff). | A | ▾
22 | Whistlers vs season
and storms (https://archive.org/details/DTIC_AD0815493)

Stanford's Navy-funded
program found whistler
delays "reduced during
magnetic storms and
lower in June than in
December" (ONR, 1967;
AFCRL, 1961). (https://archive.org/details/DTIC_AD0268166)

#21's receiver at a quiet

battery-powered site,
GPS-stamped 2-minute
recordings every hour;
measure each whistler's
dispersion and score
spectrograms blind.
A | ▾

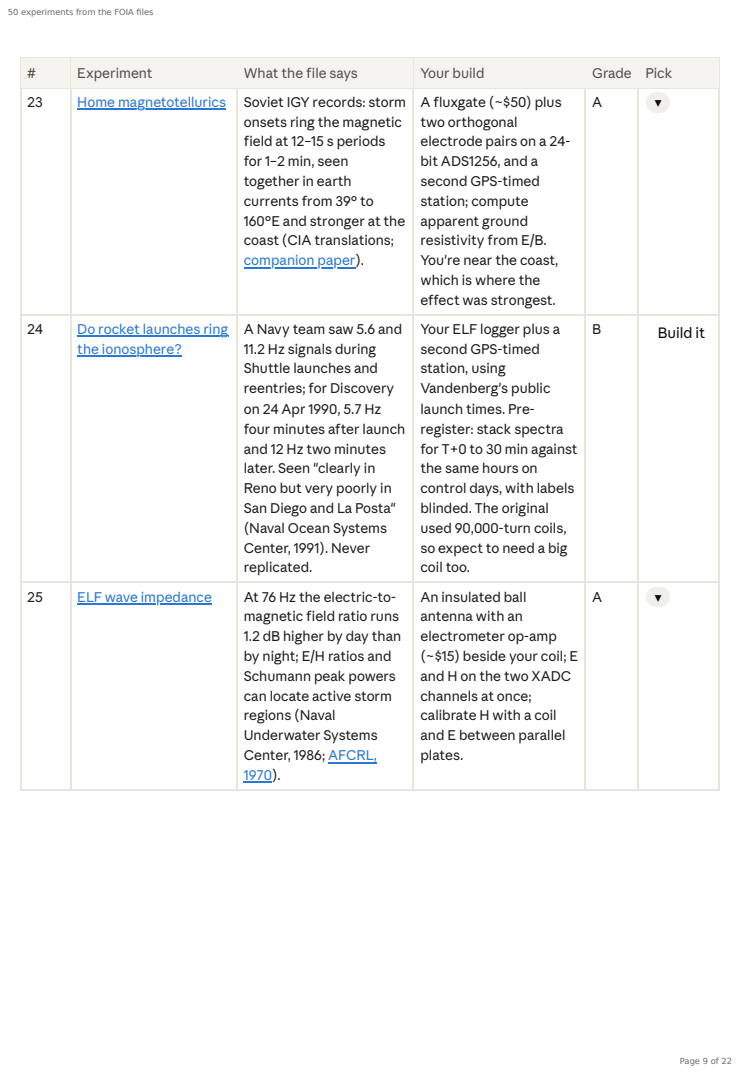
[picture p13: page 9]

23 | Home magnetotellurics (https://archive.org/details/cia-readingroom-document-cia-rdp80t00246a005400350010-3) | Soviet IGY records: storm onsets ring the magnetic field at 12–15 s periods for 1–2 min, seen together in earth currents from 39° to 160°E and stronger at the coast (CIA translations; companion paper). (https://archive.org/details/cia-readingroom-document-cia-rdp80t00246a005400350012-1) | A fluxgate (~$50) plus two orthogonal electrode pairs on a 24-bit ADS1256, and a second GPS-timed station; compute apparent ground resistivity from E/B. You're near the coast, which is where the effect was strongest. | A | ▾

24 | Do rocket launches ring the ionosphere? (https://archive.org/details/DTIC_ADA236563) | A Navy team saw 5.6 and 11.2 Hz signals during Shuttle launches and reentries; for Discovery on 24 Apr 1990, 5.7 Hz four minutes after launch and 12 Hz two minutes later. Seen "clearly in Reno but very poorly in San Diego and La Posta" (Naval Ocean Systems Center, 1991). Never replicated. | Your ELF logger plus a second GPS-timed station, using Vandenberg's public launch times. Pre-register: stack spectra for T+0 to 30 min against the same hours on control days, with labels blinded. The original used 90,000-turn coils, so expect to need a big coil too. | B | Build it

25 | ELF wave impedance (https://apps.dtic.mil/sti/pdfs/ADA167606.pdf) | At 76 Hz the electric-to-magnetic field ratio runs 1.2 dB higher by day than by night; E/H ratios and Schumann peak powers can locate active storm regions (Naval Underwater Systems Center, 1986; AFCRL, 1970). (https://archive.org/details/DTIC_AD0706873) | An insulated ball antenna with an electrometer op-amp (~$15) beside your coil; E and H on the two XADC channels at once; calibrate H with a coil and E between parallel plates. | A | ▾

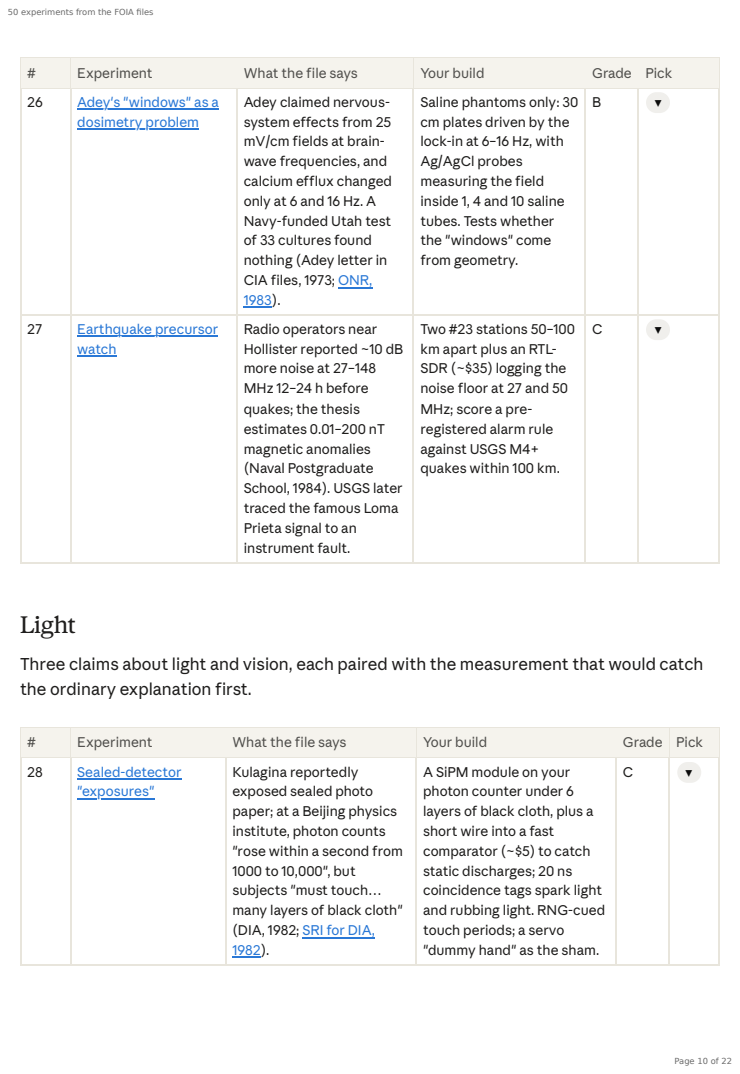
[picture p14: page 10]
Light

26 | Adey's "windows" as a dosimetry problem (https://archive.org/details/cia-readingroom-document-cia-rdp96-00787r000400080005-7) | Adey claimed nervous-system effects from 25 mV/cm fields at brain-wave frequencies, and calcium efflux changed only at 6 and 16 Hz. A Navy-funded Utah test of 33 cultures found nothing (Adey letter in CIA files, 1973; ONR, 1983). (https://archive.org/details/DTIC_ADA154599) | Saline phantoms only: 30 cm plates driven by the lock-in at 6–16 Hz, with Ag/AgCl probes measuring the field inside 1, 4 and 10 saline tubes. Tests whether the "windows" come from geometry. | B | ▾

27 | Earthquake precursor watch (https://archive.org/details/DTIC_ADA155070) | Radio operators near Hollister reported ~10 dB more noise at 27–148 MHz 12–24 h before quakes; the thesis estimates 0.01–200 nT magnetic anomalies (Naval Postgraduate School, 1984). USGS later traced the famous Loma Prieta signal to an instrument fault. | Two #23 stations 50–100 km apart plus an RTL-SDR (~$35) logging the noise floor at 27 and 50 MHz; score a pre-registered alarm rule against USGS M4+ quakes within 100 km. | C | ▾

Three claims about light and vision, each paired with the measurement that would catch
the ordinary explanation first.

# | Experiment | What the file says | Your build | Grade | Pick
28 | Sealed-detector "exposures" (https://archive.org/details/cia-readingroom-document-nsa-rdp96x00790r000100020003-3) | Kulagina reportedly exposed sealed photo paper; at a Beijing physics institute, photon counts "rose within a second from 1000 to 10,000", but subjects "must touch… many layers of black cloth" (DIA, 1982; SRI for DIA, 1982). (https://archive.org/details/cia-readingroom-document-cia-rdp96-00792r000400320001-8) | A SiPM module on your photon counter under 6 layers of black cloth, plus a short wire into a fast comparator (~$5) to catch static discharges; 20 ns coincidence tags spark light and rubbing light. RNG-cued touch periods; a servo "dummy hand" as the sham. | C | ▾

## Randomness

### The mainstream verdict is that mind-over-RNG effects aren't real: PEAR's three-lab

replication (https://www.academia.edu/6873653/Mind_Machine_Interaction_Consortium_PortREG_Replication_Experiments) came out at Z = 0.6, and a 12,571-person test (https://www.frontiersin.org/journals/psychology/articles/10.3389/fpsyg.2018.00379/pdf) favored no effect 10 to 1. These

### builds are designed so a null still tells you something, and the FPGA gives you a cleaner

random source and better timing than any of the originals had.

29 | Dermo-optics: measure the cues first (https://archive.org/details/ParaphysicsRDWarsawPact_201609) | A Soviet subject named hidden colors 113 times in 200 (chance 50) and 77 times from "a few meters"; Chinese "ear reading" claimed over 80% (DIA, 1978; SRI for DIA, 1982). (https://archive.org/details/cia-readingroom-document-cia-rdp96-00792r000400320001-8) | First measure the physical cues: an MLX90640 thermal camera ($60) and a TSL2591 light sensor ($7) check temperature differences and light leaks between colored cards. Then 200 blind trials with cards from a dark box at even temperature. | C | ▾
30 | Brownian motion and "mind power" (https://archive.org/details/cia-readingroom-document-cia-rdp96-00792r000701080001-1) | Beijing University reported that the spread of Brownian motion changed 24% under "mind power", significant only at P < 10% (qigong conference abstracts, 1988). Stokes– Einstein says 24% would need 15–20 °C of warming. | A 3D-printed OpenFlexure-style microscope (~$60) on the Orange Pi filming 1 µm beads in a sealed cell, a thermistor on the slide, drift-corrected tracking in blind RNG blocks. | C | ▾
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

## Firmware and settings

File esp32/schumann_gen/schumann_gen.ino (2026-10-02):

/*
 * schumann_gen.ino -- ESP32 calibrated ELF magnetic-field generator
 *                     (7.83 Hz "Schumann" fundamental + harmonics), with a
 *                     current-sense calibration loop, a blinded sham mode,
 *                     a magnetophosphene threshold mode, and a phone web page.
 *
 * WHAT IT IS
 *   A signal generator that drives a coil with a sum of sines at the
 *   Earth-ionosphere cavity frequencies (7.83, 14.3, 20.8, 27.3, 33.8 Hz) and
 *   KNOWS the field it makes: it measures the coil current through a sense
 *   resistor and computes the field from the coil geometry, so the display
 *   reads microtesla, not "level 7". Everything a consumer "7.83 Hz device"
 *   does not do: a stated, measured field, a real sham mode, and a log.
 *
 *   The cavity resonances are real (Schumann 1952; measured daily by ELF
 *   observatories at about 1 pT). Whether a generated field at 7.83 Hz does
 *   anything to a person is not established; this device makes no such claim.
 *   It lets you run the blinded test yourself (`blind`).
 *
 * HARDWARE (ESP32 classic: DAC on GPIO25; ESP32-S3 has no DAC -> LEDC PWM + RC)
 *   GPIO25 (DAC1)  -> waveform, 0..3.3 V centred on 1.65 V
 *                     S3: GPIO17 PWM 78 kHz 10-bit -> 10 kOhm -> 100 nF -> same
 *   coil driver: a DC-coupled power buffer (an audio amp will not pass 7.8 Hz):
 *                     DAC -> op-amp (gain 1..3, e.g. half an LM358 from a 9-12 V
 *                     supply, non-inverting, input biased at 1.65 V) -> complementary
 *                     emitter follower (BD139/BD140 or TIP31/TIP32 on a small
 *                     heatsink) -> coil -> R_SENSE -> ground
 *   GPIO34 (ADC)   <- top of R_SENSE through 10 k, 100 nF to ground (0..3.3 V!)
 *                     a 1 Ohm sense at 1 A peak = 1 V peak: fine
 *   GPIO35 (ADC)   <- optional Hall/fluxgate analog output for `verify a`
 *   GPIO27         <- optional FG-3 style fluxgate frequency output for `verify f`
 *   GPIO0 (BOOT)   button: marks the threshold in `phosphene` mode, also `stop`
 *   GPIO2          LED: on while the field is on (and in sham-on sessions)
 *
 *   Coil (default numbers, change with `coil`): 200 turns, 100 mm radius,
 *   24 AWG (about 5 Ohm). 100 mA peak gives 126 uT peak at the centre and
 *   about 45 uT at 100 mm on axis -- the Earth's field is ~50 uT.
 *
 * FIELD MATHS
 *   centre of a circular coil:  B = mu0 * N * I / (2 R)
 *   on axis at distance d:      B(d) = mu0 * N * I * R^2 / (2 (R^2 + d^2)^1.5)
 *   I is measured: I = V_sense / R_sense (ADC, 12 bit, calibrated by the ESP32
 *   core's eFuse values; `cal` trims it against a meter).
 *
 * COMMANDS (USB serial 115200, newline-terminated) -- the web page uses the same
 *   help | stat
 *   freq <Hz>                      fundamental, 0.1..100 (default 7.83)
 *   harm <n> <relative 0..1>       harmonic n = 1..5 (1 = fundamental), default 1,.5,.35,.25,.2
 *   harmonics <on|off>             all harmonics at once (default on)
 *   amp <0..1>                     output scale (DAC swing)
 *   coil <turns> <radius_mm> <rsense_ohm>
 *   target <uT_peak> [distance_mm] closed loop on the sense current to reach that field
 *   on | off
 *   verify <a|f> [uT_per_V | Hz_per_uT and Hz_at_zero]
 *                                  read the external sensor and compare with the computed field
 *   blind <sessions> <minutes>     random on/sham schedule; prints the SHA-256 commitment
 *   reveal                         prints the schedule after the sessions
 *   phosphene <f0> <f1> <seconds>  sweep f0->f1 at the set amp; press BOOT when you see flicker
 *   phosphene ramp <Hz> <seconds>  fixed frequency, amplitude 0->amp; press BOOT at threshold
 *   save | load                    settings in flash
 *   wifi <on|off>                  the phone page (AP "SCHUMANN-xxxx", password schumann1)
 *
 * MAGNETOPHOSPHENES (the `phosphene` mode)
 *   A changing magnetic field makes a faint flicker in the dark at the retina
 *   (Lovsund 1980; ICNIRP 2010): threshold about 10-20 mT peak at 20 Hz,
 *   higher either side. That is 100x this coil's field at 100 mA. To reach it
 *   you need about 5 A peak in the default coil (B = 6.3 mT at the centre;
 *   put the eye at the centre of a 100 mm coil) or 500 turns at 2 A: a real
 *   power stage, thick wire (18 AWG), and the coil gets warm (5 A into 1 Ohm =
 *   25 W peak). The phenomenon itself is harmless and reversible; the
 *   hazards are the coil temperature and the driver. The firmware limits a
 *   phosphene run to 60 s and ramps down on the button.
 *
 * STATUS: written for the ESP32 Arduino core 3.3 (esp32:esp32:esp32 and
 *   esp32:esp32:esp32s3). See the README for the compile check.
 */

#include <Arduino.h>
#include <Preferences.h>
#include <WiFi.h>
#include <WebServer.h>
#include <esp_system.h>
#include "mbedtls/sha256.h"
#include "driver/timer.h"
#if !defined(CONFIG_IDF_TARGET_ESP32)
#include "driver/ledc.h"
#define HAS_DAC 0
#else
#include "driver/dac.h"
#define HAS_DAC 1
#endif

// ------------------------------------------------------------------ pins
const int PIN_DAC    = 25;     // ESP32 classic DAC1
const int PIN_PWM    = 17;     // S3 / other: LEDC output
const int PIN_SENSE  = 34;     // ADC: coil current sense
const int PIN_HALL   = 35;     // ADC: external analog field sensor
const int PIN_FLUX   = 27;     // digital: fluxgate frequency output
const int PIN_BUTTON = 0;
const int PIN_LED    = 2;

// ------------------------------------------------------------------ synthesis
const double FS = 8000.0;                          // waveform samples per second
const int    NH = 5;
const double MU0 = 4.0e-7 * PI;
const double SCHUMANN[NH] = {7.83, 14.3, 20.8, 27.3, 33.8};   // mode centre frequencies

volatile uint32_t phase[NH] = {0, 0, 0, 0, 0};
volatile uint32_t pinc[NH]  = {0, 0, 0, 0, 0};
volatile float    hrel[NH]  = {1.0f, 0.5f, 0.35f, 0.25f, 0.2f};
volatile bool     harmOn    = true;
volatile float    ampScale  = 0.3f;                // 0..1 of the DAC swing
volatile bool     outputOn  = false;
volatile uint32_t sampleCount = 0;
volatile float    sumNorm = 1.0f;                  // 1 / sum of relative amplitudes (keeps peak <= 1)
static int16_t    sineTab[1024];

hw_timer_t *synthTimer = nullptr;
Preferences prefs;
WebServer web(80);

double fundamental = 7.83;
double coilTurns = 200, coilRadius_m = 0.100, rSense = 1.0;
double adcGainTrim = 1.0;                          // `cal` multiplies the ADC volts by this
double targetUT = 0, targetDist_m = 0;             // closed loop when > 0
bool   wifiOn = false;
bool   blindRunning = false;
String blindSchedule, blindSalt, blindCommit;
int    blindN = 0, blindMinutes = 0, blindIdx = -1;
uint32_t blindStartMs = 0;
bool   phosRunning = false, phosRamp = false;
double phosF0 = 10, phosF1 = 40, phosFixed = 20;
uint32_t phosStartMs = 0, phosDurMs = 0;
float  phosAmpMax = 0.3f;

// ------------------------------------------------------------------ ISR: one sample
void IRAM_ATTR onSynthTimer() {
  int32_t acc = 0;
  int n = harmOn ? NH : 1;
  for (int k = 0; k < n; k++) {
    phase[k] += pinc[k];
    acc += (int32_t)(sineTab[phase[k] >> 22] * hrel[k]);
  }
  float v = acc * sumNorm * ampScale / 32767.0f;      // -1..1
  if (!outputOn) v = 0;
#if HAS_DAC
  int code = 128 + (int)(v * 127.0f);
  dac_output_voltage(DAC_CHAN_0, (uint8_t)constrain(code, 0, 255));    // DAC_CHAN_0 = GPIO25
#else
  int code = 512 + (int)(v * 511.0f);
  ledcWrite(PIN_PWM, constrain(code, 0, 1023));
#endif
  sampleCount = sampleCount + 1;
}

void setFrequency(double f0) {
  fundamental = f0;
  for (int k = 0; k < NH; k++) {
    double fk = (k == 0) ? f0 : f0 * SCHUMANN[k] / SCHUMANN[0];   // harmonics scale with the fundamental
    pinc[k] = (uint32_t)(fk / FS * 4294967296.0);
  }
}

void updateNorm() {
  float s = 0;
  int n = harmOn ? NH : 1;
  for (int k = 0; k < n; k++) s += hrel[k];
  sumNorm = (s > 0) ? 1.0f / s : 1.0f;
}

// ------------------------------------------------------------------ measurement
// peak coil current from the sense resistor: sample one full fundamental period
double measurePeakCurrent() {
  uint32_t n = (uint32_t)(1000000.0 / fundamental) + 2000;   // us of one period + margin
  uint32_t t0 = micros();
  int vmax = 0, vmin = 4095;
  while (micros() - t0 < n) {
    int v = analogReadMilliVolts(PIN_SENSE);
    if (v > vmax) vmax = v;
    if (v < vmin) vmin = v;
    delayMicroseconds(200);
  }
  // the sense node swings around its DC level (unipolar driver) or around 0
  double vpk = (vmax - vmin) / 2.0 / 1000.0 * adcGainTrim;
  return vpk / rSense;
}

double fieldCentre(double ipk) { return MU0 * coilTurns * ipk / (2.0 * coilRadius_m); }
double fieldAxis(double ipk, double d) {
  double r2 = coilRadius_m * coilRadius_m;
  return MU0 * coilTurns * ipk * r2 / (2.0 * pow(r2 + d * d, 1.5));
}

// closed loop: nudge ampScale so the measured field meets the target
void serviceTarget() {
  static uint32_t last = 0;
  if (targetUT <= 0 || !outputOn || millis() - last < 1500) return;
  last = millis();
  double ipk = measurePeakCurrent();
  double b = (targetDist_m > 0 ? fieldAxis(ipk, targetDist_m) : fieldCentre(ipk)) * 1e6;
  if (b < 0.05) { Serial.println("# target: no current measured (driver off? sense wiring?)"); return; }
  double ratio = targetUT / b;
  float next = constrain(ampScale * (float)pow(ratio, 0.5), 0.0f, 1.0f);   // half-step, stable
  ampScale = next;
  if (fabs(ratio - 1.0) > 0.03)
    Serial.printf("# target %.2f uT: measured %.2f uT, amp -> %.3f\n", targetUT, b, ampScale);
  if (ampScale >= 0.999f && ratio > 1.05)
    Serial.println("# WARNING: amp at maximum and still below target: more turns, current or a closer distance");
}

// ------------------------------------------------------------------ blind / sham
String sha256Hex(const String &s) {
  unsigned char out[32];
  mbedtls_sha256((const unsigned char *)s.c_str(), s.length(), out, 0);
  String h;
  for (int i = 0; i < 32; i++) { char b[3]; snprintf(b, 3, "%02x", out[i]); h += b; }
  return h;
}

void startBlind(int n, int minutes) {
  blindSchedule = "";
  int on = n / 2;
  for (int i = 0; i < n; i++) blindSchedule += (i < on) ? 'F' : 'S';   // F = field, S = sham
  for (int i = n - 1; i > 0; i--) {                                      // Fisher-Yates with the hardware RNG
    int j = esp_random() % (i + 1);
    char t = blindSchedule[i]; blindSchedule[i] = blindSchedule[j]; blindSchedule[j] = t;
  }
  blindSalt = String((uint32_t)esp_random(), HEX) + String((uint32_t)esp_random(), HEX);
  blindCommit = sha256Hex(blindSchedule + ":" + blindSalt);
  blindN = n; blindMinutes = minutes; blindIdx = -1; blindRunning = true;
  blindStartMs = millis();
  prefs.putString("b_sched", blindSchedule);
  prefs.putString("b_salt", blindSalt);
  prefs.putString("b_commit", blindCommit);
  Serial.printf("# blind: %d sessions of %d min, half field, half sham, order drawn by the hardware RNG\n", n, minutes);
  Serial.printf("# commitment (SHA-256 of schedule:salt): %s\n", blindCommit.c_str());
  Serial.println("# write that down or send it to someone now; `reveal` after the last session shows the schedule.");
  Serial.println("# the LED and the coil current look the same in both conditions (the driver runs, the amplitude is zero in sham).");
}

void serviceBlind() {
  if (!blindRunning) return;
  uint32_t el = millis() - blindStartMs;
  int idx = el / (blindMinutes * 60000UL);
  if (idx >= blindN) {
    blindRunning = false;
    outputOn = false;
    Serial.println("# blind: all sessions done. Write down what you noticed per session, then `reveal`.");
    return;
  }
  if (idx != blindIdx) {
    blindIdx = idx;
    bool field = blindSchedule[idx] == 'F';
    outputOn = true;
    ampScale = field ? phosAmpMax : 0.0f;          // phosAmpMax doubles as the remembered amp
    Serial.printf("# session %d of %d started\n", idx + 1, blindN);
  }
}

// ------------------------------------------------------------------ phosphene mode
void servicePhosphene() {
  if (!phosRunning) return;
  uint32_t el = millis() - phosStartMs;
  if (el > phosDurMs || el > 60000) {
    phosRunning = false; outputOn = false;
    Serial.println("# phosphene: run ended without a button press (no flicker seen, or too weak)");
    return;
  }
  double x = (double)el / phosDurMs;
  if (phosRamp) {
    ampScale = (float)(phosAmpMax * x);
  } else {
    setFrequency(phosF0 + (phosF1 - phosF0) * x);
  }
  if (digitalRead(PIN_BUTTON) == LOW) {
    double ipk = measurePeakCurrent();
    Serial.printf("# THRESHOLD: %.2f Hz, amp %.3f, I_peak %.3f A, B_centre %.1f uT (%.2f mT)\n",
                  fundamental, ampScale, ipk, fieldCentre(ipk) * 1e6, fieldCentre(ipk) * 1e3);
    prefs.putString("phos_last", String(fundamental, 2) + "Hz " + String(fieldCentre(ipk) * 1e3, 2) + "mT");
    phosRunning = false; outputOn = false;
    setFrequency(7.83);
    delay(300);
  }
}

// ------------------------------------------------------------------ settings
void saveSettings() {
  prefs.putDouble("f0", fundamental);
  prefs.putFloat("amp", ampScale);
  prefs.putBool("harm", harmOn);
  for (int k = 0; k < NH; k++) prefs.putFloat((String("h") + k).c_str(), hrel[k]);
  prefs.putDouble("turns", coilTurns);
  prefs.putDouble("radius", coilRadius_m);
  prefs.putDouble("rsense", rSense);
  prefs.putDouble("trim", adcGainTrim);
  Serial.println("# saved");
}

void loadSettings() {
  setFrequency(prefs.getDouble("f0", 7.83));
  ampScale = prefs.getFloat("amp", 0.3f);
  harmOn = prefs.getBool("harm", true);
  for (int k = 0; k < NH; k++) hrel[k] = prefs.getFloat((String("h") + k).c_str(), hrel[k]);
  coilTurns = prefs.getDouble("turns", 200);
  coilRadius_m = prefs.getDouble("radius", 0.100);
  rSense = prefs.getDouble("rsense", 1.0);
  adcGainTrim = prefs.getDouble("trim", 1.0);
  updateNorm();
}

// ------------------------------------------------------------------ status
String statusJson() {
  double ipk = outputOn ? measurePeakCurrent() : 0;
  String s = "{";
  s += "\"on\":" + String(outputOn ? "true" : "false");
  s += ",\"freq\":" + String(fundamental, 3);
  s += ",\"amp\":" + String(ampScale, 3);
  s += ",\"harmonics\":" + String(harmOn ? "true" : "false");
  s += ",\"i_peak_A\":" + String(ipk, 4);
  s += ",\"b_centre_uT\":" + String(fieldCentre(ipk) * 1e6, 2);
  s += ",\"b_100mm_uT\":" + String(fieldAxis(ipk, 0.1) * 1e6, 2);
  s += ",\"coil\":{\"turns\":" + String(coilTurns, 0) + ",\"radius_mm\":" + String(coilRadius_m * 1000, 1) + ",\"rsense\":" + String(rSense, 3) + "}";
  s += ",\"target_uT\":" + String(targetUT, 2);
  s += ",\"blind\":" + String(blindRunning ? "true" : "false");
  s += ",\"phosphene\":" + String(phosRunning ? "true" : "false");
  s += ",\"samples\":" + String(sampleCount);
  s += "}";
  return s;
}

void printStat() {
  Serial.println(statusJson());
}

// ------------------------------------------------------------------ web page
const char PAGE[] PROGMEM = R"HTML(<!doctype html><html><head><meta charset=utf-8><meta name=viewport content="width=device-width,initial-scale=1">
<title>Schumann generator</title><style>body{font-family:system-ui;background:#111;color:#eee;margin:16px}
input,button{font-size:18px;margin:4px}button{padding:8px 14px}pre{background:#222;padding:8px}</style></head><body>
<h2>ELF field generator</h2>
<p>Frequency <input id=f type=number step=0.01 value=7.83 style="width:90px"> Hz &nbsp; Amplitude <input id=a type=range min=0 max=1 step=0.01 value=0.3></p>
<p><button onclick="cmd('on')">ON</button><button onclick="cmd('off')">OFF</button>
<button onclick="cmd('harmonics on')">harmonics on</button><button onclick="cmd('harmonics off')">off</button>
<button onclick="cmd('freq '+f.value)">set freq</button><button onclick="cmd('amp '+a.value)">set amp</button></p>
<p>Target field <input id=t type=number step=0.1 value=10 style="width:80px"> uT at <input id=d type=number value=100 style="width:70px"> mm
<button onclick="cmd('target '+t.value+' '+d.value)">hold</button></p>
<pre id=s>...</pre>
<script>function cmd(c){fetch('/cmd?c='+encodeURIComponent(c)).then(r=>r.text()).then(t=>{s.textContent=t})}
setInterval(()=>fetch('/status').then(r=>r.text()).then(t=>{s.textContent=t}),2000)</script></body></html>)HTML";

String handleCommandLine(String line);

void startWifi() {
  char ssid[24];
  uint64_t mac = ESP.getEfuseMac();
  snprintf(ssid, sizeof(ssid), "SCHUMANN-%04X", (unsigned)(mac & 0xFFFF));
  WiFi.mode(WIFI_AP);
  WiFi.softAP(ssid, "schumann1");
  web.on("/", []() { web.send_P(200, "text/html", PAGE); });
  web.on("/status", []() { web.send(200, "application/json", statusJson()); });
  web.on("/cmd", []() { web.send(200, "text/plain", handleCommandLine(web.arg("c"))); });
  web.begin();
  wifiOn = true;
  Serial.printf("# wifi AP %s password schumann1, page at http://%s/\n", ssid, WiFi.softAPIP().toString().c_str());
}
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
void loop() {
  static char line[96];
  static int len = 0;
  while (Serial.available()) {
    char ch = Serial.read();
    if (ch == '\n' || ch == '\r') {
      if (len > 0) { line[len] = 0; len = 0; Serial.println(handleCommandLine(String(line))); }
    } else if (len < (int)sizeof(line) - 1) {
      line[len++] = ch;
    }
  }
  if (wifiOn) web.handleClient();
  serviceTarget();
  serviceBlind();
  servicePhosphene();
  if (!phosRunning && digitalRead(PIN_BUTTON) == LOW && outputOn) {   // panic/stop button
    outputOn = false; targetUT = 0; blindRunning = false; digitalWrite(PIN_LED, LOW);
    Serial.println("# button: output off");
    delay(400);
  }
}

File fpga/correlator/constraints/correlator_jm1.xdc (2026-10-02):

#-----------------------------------------------------------------------------
# correlator_jm1.xdc -- PZ7020-StarLite constraints for correlator_top.v
#
# Board : Puzhi PZ7020-StarLite, Zynq XC7Z020-CLG400
# Part  : xc7z020clg400-2
#
# JM1 even-numbered row (BANK35, 3.3 V):
#   pin 2  3.3 V        pin 4  GND
#   pin 6  ADC A+       (E17, VAUX1P)   0 .. 1.0 V ONLY
#   pin 8  ADC A-       (D18, VAUX1N)   tie to sensor A ground
#   pin 14 UART TX      (B19)           to adapter / Teensy RX
#   pin 16 UART RX      (A20)           from adapter / Teensy TX
#   pin 18 GPS PPS      (C20)           1PPS from GPS (optional, tie low)
#
# JM1 odd-numbered row:
#   pin 9  ADC B+       (E18, VAUX9P)   0 .. 1.0 V ONLY
#   pin 11 ADC B-       (E19, VAUX9N)   tie to sensor B ground
#
# VAUX9 = IO_L5P/L5N_T0_AD9P/AD9N_35 = balls E18/E19 (PZ-StarLite schematic);
# the Puzhi "CON Pins Signal" sheet puts them on JM1 pins 9 and 11.
# JM1 pins 10/12 are F16/F17 -- plain I/O, no ADC: don't wire channel B there.
# Bank 35 is adjustable 1.8/2.5/3.3 V; these constraints assume the 3.3 V default.
#-----------------------------------------------------------------------------

## Fabric clock -- 50 MHz single-ended, IO_12P_MRCC_34
set_property PACKAGE_PIN U18      [get_ports clk_50m]
set_property IOSTANDARD  LVCMOS33 [get_ports clk_50m]
create_clock -period 20.000 -name clk_50m -waveform {0.000 10.000} [get_ports clk_50m]

## User LEDs (BANK34). High = lit.
set_property PACKAGE_PIN R19      [get_ports led_hb]
set_property IOSTANDARD  LVCMOS33 [get_ports led_hb]
set_property PACKAGE_PIN V13      [get_ports led_act]
set_property IOSTANDARD  LVCMOS33 [get_ports led_act]

## User KEY1 -- active low (BANK35). Held = fan to 100 %.
set_property PACKAGE_PIN G14      [get_ports key_n]
set_property IOSTANDARD  LVCMOS33 [get_ports key_n]
set_property PULLUP      true     [get_ports key_n]

## Fan -- same pins as the lockin design
set_property PACKAGE_PIN H16      [get_ports fan_pwm_o]
set_property IOSTANDARD  LVCMOS33 [get_ports fan_pwm_o]
set_property DRIVE       8        [get_ports fan_pwm_o]
set_property SLEW        SLOW     [get_ports fan_pwm_o]
set_property PACKAGE_PIN H17      [get_ports fan_tach]
set_property IOSTANDARD  LVCMOS33 [get_ports fan_tach]
set_property PULLUP      true     [get_ports fan_tach]
set_false_path -from [get_ports fan_tach]

## XADC auxiliary channel 1 -- JM1 pin 6 (P) / pin 8 (N) -- sensor A
set_property PACKAGE_PIN E17      [get_ports vauxp1]
set_property IOSTANDARD  LVCMOS33 [get_ports vauxp1]
set_property PACKAGE_PIN D18      [get_ports vauxn1]
set_property IOSTANDARD  LVCMOS33 [get_ports vauxn1]

## XADC auxiliary channel 9 -- JM1 pin 9 (P) / pin 11 (N) -- sensor B
## E18/E19 = AD9P/AD9N (PZ-StarLite schematic + connector pin sheet)
set_property PACKAGE_PIN E18      [get_ports vauxp9]
set_property IOSTANDARD  LVCMOS33 [get_ports vauxp9]
set_property PACKAGE_PIN E19      [get_ports vauxn9]
set_property IOSTANDARD  LVCMOS33 [get_ports vauxn9]

## UART -- JM1 pin 14 (TX out), pin 16 (RX in)
set_property PACKAGE_PIN B19      [get_ports uart_tx]
set_property IOSTANDARD  LVCMOS33 [get_ports uart_tx]
set_property DRIVE       8        [get_ports uart_tx]
set_property SLEW        SLOW     [get_ports uart_tx]
set_property PACKAGE_PIN A20      [get_ports uart_rx]
set_property IOSTANDARD  LVCMOS33 [get_ports uart_rx]
set_property PULLUP      true     [get_ports uart_rx]

## GPS PPS -- JM1 pin 18 (C20).  Tie low if no GPS connected.
set_property PACKAGE_PIN C20      [get_ports gps_pps]
set_property IOSTANDARD  LVCMOS33 [get_ports gps_pps]
set_property PULLDOWN    true     [get_ports gps_pps]

## Asynchronous inputs are synchronised in RTL
set_false_path -from [get_ports uart_rx]
set_false_path -from [get_ports key_n]
set_false_path -from [get_ports gps_pps]

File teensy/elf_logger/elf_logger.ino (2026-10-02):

/*
 * elf_logger.ino -- Teensy 4.1 extremely-low-frequency logger, 0.25 - 45 Hz
 *
 * WHAT IT DOES
 *   A modern version of the ELF monitor SRI built in 1984
 *   (CIA-RDP96-00788R001800300001-0): a sensor, x1000 of gain, an FFT, and a
 *   line of numbers every half hour. SRI had an 8-bit converter and a home
 *   computer and logged 19 frequencies from 1 to 30 Hz. This samples at 4 kHz,
 *   notches out the mains, decimates to 250 Hz, runs 4096-point spectra
 *   (0.061 Hz resolution) continuously, stamps everything with GPS time, and
 *   keeps the raw waveform so two stations can be compared sample by sample.
 *
 *   Each report gives:
 *     - the same 19 bands SRI logged (1.5625 Hz steps up to 29.7 Hz), in
 *       microvolts rms at the sensor
 *     - the strongest line near each of the first three Earth-ionosphere
 *       (Schumann) modes, about 7.8, 14 and 20 Hz, and how far each stands
 *       above the spectrum around it
 *
 * WHAT YOU HAVE TO BUILD IN FRONT OF IT
 *   The Teensy's ADC needs a signal centred on 1.65 V, within 0..3.3 V.
 *   Sensor (induction coil, or two electrodes like SRI's tree) -> differential
 *   or instrumentation amplifier with a gain of about 1000 -> a 1.65 V bias ->
 *   pin A0. Tell the sketch the gain with `gain 1000` so results come out in
 *   volts at the sensor. Put a low-pass in the amplifier or right at the pin
 *   (1.6 kOhm in series, 1 uF from A0 to GND = 100 Hz corner): the converter
 *   samples at 4 kHz and anything left near 4, 8, 12 kHz lands in the band.
 *   Battery power and distance from house wiring matter more than anything in
 *   this file.
 *
 * WIRING (Teensy 4.1)
 *   pin 14 (A0) <- amplifier output, 0..3.3 V centred on 1.65 V
 *   pin 0 (RX1) <- GPS module TX (9600 baud NMEA)        optional
 *   pin 2       <- GPS module PPS                        optional
 *   3.3 V / GND -> GPS module
 *   SD card in the Teensy's slot.
 *
 * COMMANDS (USB serial, newline-terminated)
 *   start [report_seconds]   begin logging; default report every 300 s
 *   stop
 *   live                     print the full spectrum of the current average now
 *   gain <x>                 front-end voltage gain (default 1000)
 *   mains <50|60>            mains frequency to notch (default 60)
 *   raw <on|off>             also write the 250 Hz waveform to the SD card
 *   full <on|off>            also write every report's full spectrum to the SD card
 *   stat
 *
 * FILES ON THE SD CARD
 *   ELFSPEC.CSV   one line per report: time, 19 bands, three mode lines
 *   RAWnnn.CSV    waveform, with a "PPS,<UTC>,<sample position>" line at every GPS second
 *   SPCnnn.CSV    full spectra (when `full on`)
 *
 * STATUS: compiles for Teensy 4.1 (Teensyduino 1.62). Filters, spectra, report and
 *   GPS stamping run on a PC against a simulated front end. Not yet run on hardware.
 */

#include <Arduino.h>
#include <SD.h>
#include <arm_math.h>

const int    PIN_ADC  = 14;       // A0
const int    PIN_PPS  = 2;
const double FS_ADC   = 4000.0;   // ADC sample rate
const int    DECIM    = 16;
const float  FS_OUT   = 250.0f;   // after decimation
const int    NFFT     = 4096;
const int    HOP      = 2048;
const int    NBINS    = 760;      // up to 46 Hz
const float  ADC_LSB  = 3.3f / 4096.0f;

// ----------------------------------------------------------------- filters
struct Biquad {
  double b0 = 1, b1 = 0, b2 = 0, a1 = 0, a2 = 0, z1 = 0, z2 = 0;
  inline double step(double x) {                      // transposed direct form II
    double y = b0 * x + z1;
    z1 = b1 * x - a1 * y + z2;
    z2 = b2 * x - a2 * y;
    return y;
  }
  void notch(double f0, double q, double fs) {
    double w = 2.0 * PI * f0 / fs, al = sin(w) / (2.0 * q), a0 = 1.0 + al;
    b0 = 1.0 / a0; b1 = -2.0 * cos(w) / a0; b2 = 1.0 / a0;
    a1 = -2.0 * cos(w) / a0; a2 = (1.0 - al) / a0;
    z1 = z2 = 0;
  }
  void lowpass(double f0, double q, double fs) {
    double w = 2.0 * PI * f0 / fs, al = sin(w) / (2.0 * q), a0 = 1.0 + al;
    b0 = (1.0 - cos(w)) / 2.0 / a0; b1 = (1.0 - cos(w)) / a0; b2 = b0;
    a1 = -2.0 * cos(w) / a0; a2 = (1.0 - al) / a0;
    z1 = z2 = 0;
  }
};
Biquad notchF[3];      // mains and its 2nd and 3rd harmonics
Biquad lpF[4];         // 8th-order Butterworth low-pass at 45 Hz: with 60 Hz mains the
                       // 240 Hz harmonic folds to 10 Hz after decimation, this puts it 116 dB down
double mainsHz = 60.0;

// ----------------------------------------------------------------- sampling
IntervalTimer adcTimer;
const int FIFO_N = 1024;
volatile float    fifo[FIFO_N];
volatile uint32_t fifoHead = 0, fifoTail = 0, fifoDrops = 0;
volatile uint32_t adcCount = 0;            // 4 kHz sample counter
volatile int      decimPhase = 0;
volatile int      adcMin = 4095, adcMax = 0;
volatile uint32_t ppsCount = 0, ppsAdcIndex = 0;
volatile bool     ppsFlag = false;

// ----------------------------------------------------------------- spectra
arm_rfft_fast_instance_f32 fftInst;
float  win[NFFT];
double winSumSq = 0, winSum = 0;
float  ring[NFFT];
int    ringPos = 0;
long   ringCount = 0;
float  fftIn[NFFT], fftOut[NFFT];
double Pxx[NBINS];
float  respCorr[NBINS];                     // 1 / |filter response|^2 at each bin
int    nSeg = 0;

// ----------------------------------------------------------------- state
float  gainFront = 1000.0f;
bool   logging = false, rawWanted = false, fullWanted = false, sdOk = false;
uint32_t reportMs = 300000;
elapsedMillis sinceReport;
File   rawFile;
bool   rawOpen = false;
uint32_t outIndex = 0;                      // 250 Hz sample counter
uint32_t reportNo = 0;

// GPS
char   nmea[100];
int    nmeaLen = 0;
bool   gpsValid = false;
char   gpsStamp[24] = "";                   // 20yy-mm-ddThh:mm:ssZ
elapsedMillis gpsAge;
bool   ppsPending = false;                  // a PPS edge is waiting for its time sentence
double ppsPendingIdx = 0;
elapsedMillis ppsPendingAge;

// =================================================================== ISRs
void adcISR() {
  int code = analogRead(PIN_ADC);
  if (code < adcMin) adcMin = code;
  if (code > adcMax) adcMax = code;
  double x = (double)code;
  x = notchF[0].step(x);
  x = notchF[1].step(x);
  x = notchF[2].step(x);
  x = lpF[0].step(x);
  x = lpF[1].step(x);
  x = lpF[2].step(x);
  x = lpF[3].step(x);
  adcCount++;
  if (++decimPhase >= DECIM) {
    decimPhase = 0;
    uint32_t next = (fifoHead + 1) % FIFO_N;
    if (next == fifoTail) fifoDrops++;
    else { fifo[fifoHead] = (float)x; fifoHead = next; }
  }
}

void ppsISR() {
  ppsAdcIndex = adcCount;
  ppsCount++;
  ppsFlag = true;
}

// |H|^2 of one biquad at frequency f
double biquadPower(const Biquad &q, double f) {
  double w = 2.0 * PI * f / FS_ADC, c1 = cos(w), s1 = sin(w), c2 = cos(2 * w), s2 = sin(2 * w);
  double nr = q.b0 + q.b1 * c1 + q.b2 * c2, ni = -(q.b1 * s1 + q.b2 * s2);
  double dr = 1.0 + q.a1 * c1 + q.a2 * c2, di = -(q.a1 * s1 + q.a2 * s2);
  return (nr * nr + ni * ni) / (dr * dr + di * di);
}
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
